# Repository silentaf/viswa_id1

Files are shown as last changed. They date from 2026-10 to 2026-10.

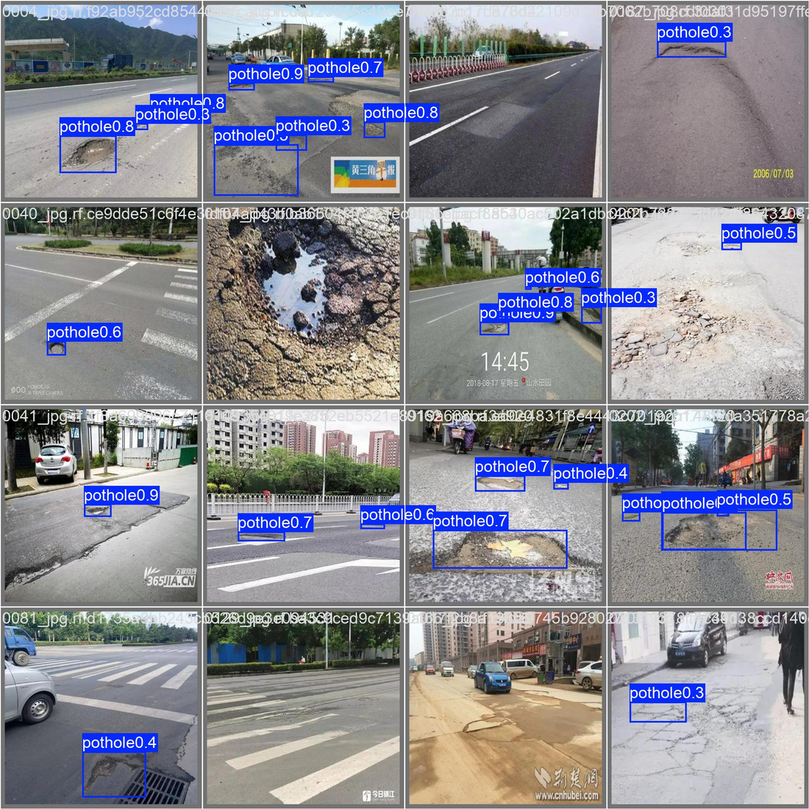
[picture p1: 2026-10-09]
ppt/assets/pothole_test_pred.png

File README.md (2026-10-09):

# VisionAid: Vishwakarma Awards 2026–27 (Team SVNIT)

A chest-worn, fully offline navigation aid for blind and low-vision users that **adds head-level-obstacle and drop-off warnings to the white cane**.
- An **FPGA safety island** (Tang Nano 9K) keeps the alert path running even if the AI computer fails.
- An on-device AI layer (Raspberry Pi 5) names hazards and reads text aloud.

**Stage 2: Design Development.** This repository holds the design files. Nothing has been fabricated yet. Every number is labelled *target*, *calculated*, *simulated*, *cited* or *measured on the development laptop* (Pi software, not a Pi 5); none is a measurement on VisionAid hardware.

| Path | Contents |
|---|---|
| [`VisionAid_Proposal_v2.md`](VisionAid_Proposal_v2.md) | Design specification v2: the Stage 1 proposal corrected, with every change explained |
| [`IMPLEMENTATION_PLAN.md`](IMPLEMENTATION_PLAN.md) | Stage 2 plan, gates, slide map, checklist |
| [`design/electronics/`](design/electronics/) | KiCad 9 carrier board: schematic, PCB, Gerbers, BOM, STEP (ERC 0 / DRC 0) |
| [`design/fpga/`](design/fpga/) | Verilog safety island, testbench (all tests pass), waveforms, Yosys utilisation |
| [`design/cad/`](design/cad/) | FreeCAD parametric chest pod, STEP/STL, renders, mount FEA |
| [`design/bom/`](design/bom/) | Prototype BOM and power budget (xlsx) |

All design files are generated by the scripts in each folder (`scripts/`), so every design decision is written down and reproducible. See [`design/README.md`](design/README.md) for the tools and how to open each file.

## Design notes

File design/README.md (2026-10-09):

# VisionAid: Stage 2 Design Files (index)

**Everything here is design-stage work.** It contains no hardware measurements. Each number is labelled **simulated**, **calculated**, **estimate** or **target**.

| Folder | What | Key result | Feeds slide |
|---|---|---|---|
| `electronics/` | KiCad 9 carrier board: schematic, PCB, Gerbers, BOM, 3D STEP | ERC 0 · DRC 0 · 0 unconnected · parity 0 · 100 % routed | 5, 9, 10, 12 |
| `fpga/` | Verilog safety island, testbench, waveform plots, Yosys utilisation | ALL TESTS PASSED; echo → motor 136 ns on the waveform, ≤ 214 ns testbench bound (simulated); P&R: LUT 17 %, FF 8 %, Fmax 67.9 MHz | 5, 6, 12, 16 |
| `cad/` | FreeCAD parametric pod (`VisionAid_Pod.FCStd`), STEP/STL, renders, mount FEA | 0 mm³ interference; FEA convergence + v1 → v2 iteration | 7, 8, 12 |
| `bom/` | `VisionAid_BOM_Power.xlsx`: prototype BOM + power budget | ₹33,945 at 9 Oct 2026 quotes (₹3,945 over the grant; budget rule inside); 7.2 W → 4.3 h assuming ~50 % AI duty (calculated) | 6, 10 |
| `../VisionAid_Proposal_v2.md` | Corrected Stage 1 document | 15 documented changes | 1–4, 13 |
| `../IMPLEMENTATION_PLAN.md` | Plan, gates, slide map, checklist | — | all |

## Tools (installed locally in `../tools/`, no root needed)

| Tool | Launcher | Used for |
|---|---|---|
| KiCad 9.0.8 | `tools/kicad.sh kicad design/electronics/VisionAid_Carrier.kicad_pro` | Schematic / PCB GUI |
| FreeCAD (conda-forge) | `tools/freecad.sh gui design/cad/VisionAid_Pod.FCStd` | CAD GUI, feature tree, FEM |
| Icarus Verilog, GTKWave, Yosys | `tools/eda.sh <tool>` | Simulation, waveforms, synthesis |
| FreeRouting 2.5 | used by `electronics/scripts/route_pcb.py` | PCB autorouting |

## What YOU must do yourself (judges check authenticity)

1. **Open every design in the GUI and make at least one real edit of your own.** For example: tidy silkscreen in KiCad, change a fillet in FreeCAD, add a comment in the Verilog. Save, then commit.
2. **Take your own screenshots:**
   - FreeCAD with the **feature tree** (BaseShell → ShellProfile sketch, ShellPad, CornerFillet, Hollow, …) and the Params spreadsheet;
   - KiCad PCB editor + 3D viewer + the DRC dialog showing 0 errors;
   - GTKWave with the latency signals;
   - the FreeCAD FEM result.
3. **Photos with your SVNIT ID badge on:** you at the laptop doing CAD / KiCad / simulation, and a review with your faculty guide (photo or video-call screenshot).
4. **Git:** put this `design/` folder in a GitHub repo and commit regularly until 24 Oct. File dates are audited, so do not upload everything on the last day.
5. **Be able to explain every block.** Read `electronics/README.md` and `fpga/README.md`, and the "why" column of the plan.

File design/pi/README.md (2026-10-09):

# VisionAid Raspberry Pi Software (AI path): Proof of Concept

**What this is:**
- The Python application that will run on the Raspberry Pi 5.
- It has been **run and measured on the development laptop** (Intel i7-14650HX, ONNX Runtime limited to 4 threads to match the Pi 5's 4 cores).
- **Speeds are laptop numbers, not Pi 5 numbers.** Expect the Pi 5 to be slower; it will be measured in Stage 3.
- **Accuracy numbers do not depend on the computer.**

| Module | File | Function |
|---|---|---|
| Protocol | `visionaid_pi/protocol.py` | FPGA ↔ Pi UART frames, matching `rtl/va_pilink.v` byte for byte |
| Floor baseline | `visionaid_pi/floor.py` | IMU pitch → expected LiDAR floor range → command to the FPGA (prevents walking-sway false alarms) |
| Vision | `visionaid_pi/vision.py` | YOLOv5n (COCO) on ONNX Runtime; only mobility hazards are named; left / ahead / right from box position |
| Speech | `visionaid_pi/speech.py` | RapidOCR (PP-OCR ONNX) text reading; Piper offline neural TTS (English, Hindi) |
| Alerts | `visionaid_pi/alerts.py` | Priorities: safety > hazard name + FPGA distance > text. The Pi never drives the motors. |
| App | `visionaid_pi/app.py` | Main loop: **event-triggered AI** (runs detection only when the FPGA reports < 3 m), heartbeat, replay mode |

## Measured results (`results/bench_results.json`, `results/detection_accuracy.json`)

| Check | Result | How |
|---|---|---|
| **FPGA ↔ Pi protocol** | **192 frames decoded, 0 bad**; drop-off and fault flags correct; **the Python-built command was accepted by the Verilog FPGA** | Bytes recorded from the Verilog testbench (`../fpga/sim/fpga_to_pi_bytes.hex`); the command bytes come from `protocol.build_command` |
| Detection speed | 28 ms per 640×640 frame (p95 29 ms) | 24 COCO images, laptop |
| **Detection accuracy** | mAP50 **0.41** over 12 hazard classes; **person: AP50 0.65, precision 0.85 and recall 0.54 overall; recall 0.82 for people larger than 96 × 96 px in the image**; weak on bench and truck | 200 COCO val2017 images vs human labels, IoU ≥ 0.5 |
| **OCR accuracy** | **1.9 %** character error (clean), **1.8 %** (blur + tilt + noise); 72–75 % of lines exactly right | 64 rendered labels with known text (synthetic bench test) |
| OCR speed | 1.2–1.4 s per label | laptop |
| TTS | English 150–270 ms, Hindi 85–150 ms to synthesise 1.6–3 s of speech | Piper, laptop |
| **End to end** | camera image → detection → alert → speech WAV ready: **211 ms** mean | laptop |
| Full loop replay | FPGA simulation bytes + images → "Step down ahead. Stop.", "Check device: head sensor.", "person, left, 1.6 metres" | `results/replay/` (log + WAV files) |

**A bug found by the tests and fixed:** OCR word order. Words on one line were sorted by box top, so "BUS STOP" came out as "STOP BUS". Character error went from 25.8 % to 1.9 % after the fix.

**Limitations (honest):**
- Synthetic OCR labels are cleaner than real photos.
- COCO has no Indian classes (auto-rickshaw, open drain).
- Hindi OCR needs a Devanagari model.

All three are Stage 3 work.

## Model training: pothole detector (`training/`)

COCO has no pothole class, so we fine-tuned **YOLO11n** (COCO-pretrained start) on a public pothole dataset
(Roboflow Universe "Potholes Detection", CC BY 4.0, via Hugging Face `Ryukijano/Pothole-detection-Yolov8`;
100 train / 100 valid / 100 test images). Train and test were checked for overlap by file name and by perceptual
hash, including flipped copies: none. 100 epochs on an RTX 5060 laptop GPU took 7.7 min.

| Held-out test split (100 images, 269 potholes) | Result |
|---|---|
| Precision / recall | 0.64 / 0.30 |
| mAP50 / mAP50-95 | 0.37 / 0.15 |
| ONNX speed, laptop CPU, 4 threads (not Pi 5) | 26 ms per image |

Honest limits: a small dataset of mostly non-Indian road photos taken from vehicle or hand height, so recall is low.
Stage 3 needs Indian, chest-height images from our own camera. Files: `training/results/pothole_metrics.json`,
curves, test predictions, `pothole_yolo11n.onnx`. Run: `tools/train-env/bin/python design/pi/training/train_pothole.py`
(from `tools/train-runs/`).

## Run

```
tools/pi-env/bin/python design/pi/bench.py               # benchmark
tools/pi-env/bin/python design/pi/eval_detection.py      # accuracy vs COCO
cd design/pi && ../../tools/pi-env/bin/python -m visionaid_pi.app --replay ../fpga/sim/fpga_to_pi_bytes.hex --images test_data/coco
```

**Test images:** `test_data/coco` is COCO val2017 (Flickr, Creative Commons; cocodataset.org).

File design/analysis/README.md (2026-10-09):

# Design Analyses (calculation and simulation, not hardware measurements)

## `sensor_geometry.py` → `sensor_geometry.png`, `sensor_geometry.json`

**Assumptions:**
- pod height 1.30 m (adult);
- ultrasonic half-beam angle 15°;
- angles taken from the CAD: head sensor +25°, sides ±15°, LiDAR −35°.

**Drop-off warning:**
- The LiDAR meets the floor **1.86 m ahead**.
- A 15 cm step raises the range by 26 cm, so the step is flagged when its edge is about **1.86 m ahead** (≈ 1.5 s at 1.2 m/s).
- **The ≥ 1 m target is met (calculated).**

**Walking sway (simulated):**
- With ±3° chest sway, the floor range swings by up to 30 cm.
- **With a fixed floor baseline there were 25 false alarms in 20 s. With an IMU-compensated baseline there were 0.**
- → Implemented in `design/pi/visionaid_pi/floor.py`. The IMU is required, not optional.

**Coverage gap found:**
- Close to the user (< 1 m ahead), heights **0.3–1.0 m** (waist level) are not covered: the cane covers < 0.3 m and the forward beams reach down to only about 1.0 m there.
- **Fix for CAD v2:** tilt the forward sensors down by 10°.
- Until then, the camera can name such objects but the FPGA reflex path will not catch them.

## `power_range.py` → `power_range.json`

Uses the **published** Pi 5 figures: ≈ 3.0 W idle and ≈ 8.8 W full load (raspberry.tips, 2026). The rest of the system is ≈ 1.3 W (datasheet-level estimates), on a 37 Wh bank at 85 % efficiency.

| Mode | Total | Runtime |
|---|---|---|
| AI running continuously | 10.1 W | **3.1 h** |
| **Event-triggered AI (design choice; AI busy ~50 %, assumed)** | 7.2 W | **4.3 h** |
| AI mostly idle | 4.3 W | 7.2 h |

**Conclusion:** the ≥ 4 h target needs event-triggered AI. This is implemented in `design/pi/visionaid_pi/app.py`.

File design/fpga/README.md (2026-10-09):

# VisionAid FPGA Safety Island (Tang Nano 9K, Verilog)

**Status (8 Oct 2026):**
- Simulation only, so all numbers here are **simulated**, not hardware measurements.
- `run_sim.sh` reports **ALL TESTS PASSED**.

## What it does

| Module | File | Function |
|---|---|---|
| `va_ultrasonic` | `rtl/va_ultrasonic.v` | Fires 3 RCWL-1601 sensors **one at a time** (no crosstalk), 33 ms slots (99 ms per direction). Times the echo in µs and converts it to mm with `(t × 11239) >> 16` = t × 0.1715. Flags a dead or unplugged sensor after 3 missed responses. |
| `va_zone` | `rtl/va_alerts.v` | Distance → zone (info < 3 m, warn < 2 m, urgent < 1 m). Escalates **immediately**; de-escalates with 50 mm hysteresis. |
| `va_haptic` | `rtl/va_alerts.v` | Pulse rate encodes distance: urgent = continuous, warn = 5 Hz, info = 2 Hz. The pattern restarts in its ON phase when the zone escalates, so the motor turns on in the same clock cycle. PWM limits the 3 V motors. |
| `va_lidar` | `rtl/va_alerts.v` | TF-Luna 9-byte frame parser (checksum + signal-strength check). Drop-off = floor reading ≥ 15 cm beyond the calibrated baseline for 3 frames. |
| `va_watchdog` | `rtl/va_alerts.v` | No Pi heartbeat edge for 750 ms → "AI offline" chirp. **Alerts keep working.** |
| `va_pilink` | `rtl/va_pilink.v` | 115200-baud link: status frame to the Pi every 20 ms; commands from the Pi with **clamped** limits (the Pi cannot disable alerts). |
| `visionaid_top` | `rtl/visionaid_top.v` | Ties the blocks together: synchronisers, debouncing, quiet mode (silences only the "info" level), buzzer patterns, LEDs. |

## Simulated results (`sim/sim_results.log`)

| Check | Result |
|---|---|
| Distance 1500 / 2500 mm | 1499 / 2499 mm |
| **Echo edge → motor on** | **136 ns** on the plotted waveform event (motor rises on the same clock as the zone change). The testbench monitor reports **max 214 ns** over 4 events, a conservative bound: it samples the motor 2 clocks after the zone change. Target ≤ 1 ms. |
| Status frames to the Pi | 192 OK, 0 bad (Verilog decoder and Python decoder agree) |
| Drop-off alert | 22.3 ms after the floor reading changed |
| Pi heartbeat lost | AI offline flagged at 666 ms; the obstacle alert still worked |
| Unplugged sensor | fault flag + FAULT_N low |

Figures: `sim/waveform_overview.png`, `sim/waveform_latency_zoom.png` (made by `plot_waveforms.py`).

## Real implementation on the Tang Nano 9K chip (`run_impl.sh` → `impl/`)

The open-source flow ran for **GW1NR-LV9QN88PC6/I5**: Yosys `synth_gowin`, then nextpnr-himbaechel (place and route, timing), then Project Apicula `gowin_pack`.

| Result | Value |
|---|---|
| Timing at the 27 MHz board clock | **PASS**. Fmax **67.9 MHz** (about 2.5× margin) |
| LUT4 | 1,512 / 8,640 (**17 %**) |
| ALU | 914 / 6,480 (14 %) |
| Flip-flops | 568 / 6,480 (**8 %**) |
| I/O | 26 / 276 |
| Bitstream | `impl/visionaid.fs`. Ready to load with openFPGALoader / Gowin programmer when the board arrives. |

## Cross-check in AMD Vivado 2026.1 (`vivado/`)

The same RTL was synthesised and implemented out-of-context on a **Zynq-7020 (xc7z020clg400-1)** at 27 MHz:
- **all timing constraints met, WNS +30.2 ns**;
- 653 LUTs (1.2 %), 580 flip-flops, 1 DSP.

## FPGA ↔ Pi cross-verification

- The testbench sends a command whose bytes were **generated by the Python Pi software** (`tb/pi_cmd_from_python.hex`). The FPGA accepted it (T4).
- Every byte the FPGA transmits is recorded (`sim/fpga_to_pi_bytes.hex`). The Python decoder decodes **192 / 192** frames, matching the Verilog-side decoder.

## Run

```
./run_sim.sh                                                   # ~10 min: simulates 3.9 s of operation
../../tools/eda.sh gtkwave sim/visionaid.vcd                   # waveforms (screenshot for the PPT)
python3 plot_waveforms.py                                      # PNG figures
```

Pin constraints: `constraints/visionaid_tangnano9k.cst`. They match the carrier-board schematic.

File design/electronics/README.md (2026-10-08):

# VisionAid Carrier Board: Electronics Design (v0.1, design stage)

**Status (8 Oct 2026):**
- **Designed and verified in KiCad 9:** ERC 0 violations; DRC 0 violations; 0 unconnected; schematic ↔ PCB parity 0 issues.
- **Not fabricated or tested yet.** Every number below is a design value or target, not a measurement.

## What this board does

It is the **interface and safety-island board** that sits on top of the Raspberry Pi 5 in the chest pod.

| Block | Parts | Why it is designed this way |
|---|---|---|
| **FPGA safety island** | U1 Sipeed Tang Nano 9K (GW1NR-9, 27 MHz) on 2 × 24 sockets | Times all 3 ultrasonic echoes **in parallel** and drives the motors **without the Pi**. If Linux or the AI crashes, obstacle alerts continue (watchdog on `PI_HB`). Only **3.3 V-bank pins** on the left header are used; the right-header pins marked `_1V8` are on a 1.8 V bank and are unused. |
| **Pi link** | J1 2 × 20 header → 40-way IDC ribbon → Pi GPIO | UART (GPIO14/15) for status and config, GPIO17 = heartbeat to the FPGA, GPIO27 = fault from the FPGA, I²C (GPIO2/3) for the IMU. |
| **Power** | F1 500 mA PTC, U2 AMS1117-3.3, C1–C5, D1 SS14 | 5 V comes from the Pi header (the Pi is powered by a BIS-certified USB-C power bank). The PTC protects the Pi's 5 V rail if this board shorts. A separate 3.3 V regulator means the Pi's 3.3 V pins (1, 17) are deliberately **not** used. D1 stops back-feed when the Tang Nano's own USB-C is plugged in for programming. |
| **Sensors** | J2–J4 RCWL-1601 ultrasonic (left, right, head-level), J5 TF-Luna LiDAR (drop-offs), J8 MPU-6050 IMU | RCWL-1601 works at 3.3 V, so there is no level shifting. The TF-Luna takes 5 V but has 3.3 V UART logic. 100 Ω series resistors (R7–R14) limit fault current and ringing on the cables. |
| **Haptics and alarm** | Q1–Q3 AO3400A, R1–R6, D2–D4, J6/J7 coin motors, BZ1 buzzer | Logic-level MOSFETs (V_GS(th) ≤ 1.45 V) are switched directly by the FPGA's 3.3 V PWM. 100 kΩ pull-downs keep the motors off while the FPGA boots. Flyback diodes protect the MOSFETs. The motors (3 V coin ERMs) run from +3V3. |
| **Buttons** | J9 (READ = OCR, MODE, QUIET), R15–R17 10 k pull-ups, C7–C9 100 nF | 10 k × 100 nF ≈ 1 ms RC filter, plus digital debounce in the FPGA. |
| **Test points** | TP1–TP6 (+5V, +3V3, GND, US_L_ECHO, MOT_L_G, PI_HB) | For the Stage 3 logic-analyser measurement of **echo → motor-on latency** and for power checks. |

## FPGA pin map (Tang Nano 9K, 3.3 V banks only)

| Signal | FPGA pin | Signal | FPGA pin |
|---|---|---|---|
| US_L_TRIG / ECHO | 25 / 26 | PI_TXD (FPGA RX) / PI_RXD (FPGA TX) | 40 / 35 |
| US_R_TRIG / ECHO | 27 / 28 | PI_HB (heartbeat in) | 41 |
| US_H_TRIG / ECHO | 29 / 30 | FPGA_FAULT_N (out to Pi) | 42 |
| LIDAR_TX / LIDAR_RX | 33 / 34 | MOT_L_PWM / MOT_R_PWM / BUZZ_EN | 51 / 53 / 54 |
| Clock 27 MHz (on module) | 52 | BTN_READ / MODE / QUIET | 55 / 56 / 57 |

Source: the Sipeed Tang Nano 9K official pin map (wiki.sipeed.com).

## PCB

- **Outline:** 85 × 56 mm, 2 layers, 1.6 mm FR-4. It has the **same outline and M2.5 mounting holes as the Raspberry Pi 5**, and is stacked above the Pi on **20 mm standoffs**. Those clear the Pi's USB/Ethernet jacks and the active cooler; a standard HAT would hit them.
- **Layout:**
  - The Tang Nano sits on 8.5 mm sockets, with its USB-C flush at the right edge for programming.
  - Low-profile SMD parts sit **under** the module, between the socket rows.
  - Sensor connectors are on the bottom edge (cables exit downward towards the sensor windows). Buttons, IMU and motor connectors are on the left edge.
- **Track rules:**
  - 5 V and GND: 0.5 mm.
  - +3V3: 0.3 mm (about 250 mA total load).
  - Signals: 0.25 mm (minimum 0.15 mm, where the router necks down at pads).
  - Clearance 0.2 mm; vias 0.6/0.3 mm.
  - GND pours on both layers.
- **Routing:** FreeRouting v2.5.0 completed 100 %, with 0 violations.

## How the files are produced (reproducible)

All files are generated from scripts so every design decision is written down:

```
tools/kicad.sh python design/electronics/scripts/gen_library.py    # Tang Nano symbol + footprint
python3 design/electronics/scripts/gen_schematic.py                # schematic (.kicad_sch)
tools/kicad.sh kicad-cli sch export netlist -o design/electronics/VisionAid_Carrier.net design/electronics/VisionAid_Carrier.kicad_sch
tools/kicad.sh python design/electronics/scripts/gen_pcb.py        # outline, placement, nets
tools/kicad.sh python design/electronics/scripts/route_pcb.py      # FreeRouting + GND pours
```

Open the project in the KiCad GUI with `tools/kicad.sh kicad design/electronics/VisionAid_Carrier.kicad_pro`.

## Outputs (`outputs/`)

| File | Contents |
|---|---|
| `VisionAid_Carrier_schematic.pdf` / `.svg` | Schematic |
| `VisionAid_Carrier_pcb_top.pdf` / `_bottom.pdf` | Copper and silkscreen plots |
| `gerbers/` | Fabrication files (Gerber X2 + Excellon drill + drill map) |
| `VisionAid_Carrier_BOM.csv` | Bill of materials (on-board parts) |
| `VisionAid_Carrier_pos.csv` | Pick-and-place positions |
| `VisionAid_Carrier.step` | 3D model for the enclosure CAD |
| `pcb_3d_top.png` / `pcb_3d_iso.png` | Board renders with component 3D models (Tang Nano 9K: simplified model in `3d/`) |
| `ERC_report.txt` / `DRC_report.txt` | Verification reports |

## Not on the PCB BOM (buy separately in Stage 3)

- 2 × 1×24 female headers (2.54 mm, 8.5 mm tall) for the Tang Nano.
- 40-way IDC ribbon cable with 2 sockets (≈ 10 cm).
- 4 × M2.5 × 20 mm standoffs and screws.
- JST-XH housings and crimps.
- The sensors, motors and buttons themselves (see the implementation plan, §5).

## Open items before fabrication (Stage 3)

1. **Measure the Tang Nano 9K header row spacing with calipers.** The footprint uses 22.86 mm (0.9″), taken from a community footprint, not an official drawing.
2. Confirm the ribbon length and the standoff height against the enclosure CAD.
3. Check the AMS1117 dropout and temperature at the real load: 5 V → 3.3 V at ~250 mA ≈ 0.43 W in SOT-223.
4. Review the board in the KiCad GUI: tidy silkscreen, then re-run DRC.

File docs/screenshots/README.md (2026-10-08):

# GUI screenshots (8 Oct 2026)

These were captured from the real applications running on a virtual display on the team laptop, using the project files in this repo.

| File | Shows |
|---|---|
| `freecad_01_feature_tree_finger_fillet.png` | FreeCAD PartDesign feature tree; the new `FingerRootFillet` (R 1.5 mm, from the FEA iteration) on the GoPro mount |
| `freecad_02_assembly_iso.png` | Full pod assembly in FreeCAD |
| `freecad_03_params_spreadsheet.png` | Parameter spreadsheet that drives the model |
| `freecad_04_sketch_constraints.png` | Shell profile sketch: **fully constrained**, width/height driven by spreadsheet expressions |
| `kicad_01_pcb_editor_unrouted0.png` | KiCad PCB editor; status bar shows **Unrouted 0** |
| `kicad_02_drc_dialog.png` | KiCad Design Rules Checker: **0 violations, 0 unconnected** |
| `kicad_03_3d_viewer.png` | KiCad 3D viewer with component models, incl. a simplified Tang Nano 9K model made for this project (`design/electronics/3d/`) |
| `kicad_04_schematic.png` | Full schematic |
| `kicad_05_erc_dialog.png` | KiCad Electrical Rules Checker: **0 errors, 0 warnings** |
| `gtkwave_01_echo_to_motor_latency.png` | GTKWave (simulation): left echo falls → distance register = 0x02ED (749 mm) → zone 2 → 3 → left motor ON within a few 37 ns clock cycles |

Still to add, taken by the team: photos with SVNIT ID badges, and the faculty-guide review.

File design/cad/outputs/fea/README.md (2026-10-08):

# Chest-mount FEA (simulation, design stage)

**Tools:** FreeCAD FEM, Gmsh (2nd-order tetrahedra) and CalculiX. Script: `design/cad/scripts/fea_mount.py`. Plots: `plot_fea.py`.

**Model:** a GoPro-style 2-finger mount (3.0 mm fingers, 3.2 mm gap, M5 bolt) on a 30 × 30 mm piece of the 2.5 mm back wall.

**Material:** PETG, E = 2.0 GPa, ν = 0.38. Yield is about 50 MPa (typical datasheet value). Printed parts are weaker between layers, so we **require a factor of safety (FoS) ≥ 3**.

**Boundary conditions:** the bolt-hole faces are fixed (held by the harness buckle). The load is applied on the wall face.

**Load cases (design assumptions):**
- A: **50 N downward.** A ~0.3 kg pod at ~17 g, i.e. a bump or snag.
- B: **20 N sideways.** A side knock, which bends the thin fingers.

## Results (finest mesh that solved)

| Version | Load | Elements | Max von Mises (MPa) | Finger-root (MPa) | FoS on 50 MPa | Max deflection (mm) |
|---|---|---|---|---|---|---|
| v1 sharp roots | A 50 N down | 19,477 | 5.77 | 2.20 | 8.7 | 0.064 |
| v1 sharp roots | B 20 N side | 19,337 | 5.12 | 2.52 | 9.8 | 0.032 |
| v2 1.5 mm root fillet | A 50 N down | 13,572 | 5.74 | 1.76 | 8.7 | 0.062 |
| v2 1.5 mm root fillet | B 20 N side | 13,509 | 4.04 | 2.40 | 12.4 | 0.029 |

## What the convergence study shows (`fea_convergence.png`)

- **v1 (sharp roots):** the finger-root stress **keeps rising as the mesh is refined**: 1.59 → 2.20 MPa under load A and 1.62 → 2.52 MPa under load B. That is the signature of a **stress singularity at a sharp corner**. The true peak in a printed part is set by the corner radius, so the v1 result cannot be trusted.
- **v2 (1.5 mm root fillet):** the root stress **converges** to 1.76–1.82 MPa under A and 2.40–2.42 MPa under B, with < 3 % change across meshes.
- **Design iteration:** v1 → v2 adds 1.5 mm fillets at the finger roots. This is now in the pod CAD as the `FingerRootFillet` feature (8 edges, R 1.5 mm).
- **Where the peak sits:** the highest stress (~4–6 MPa) is at the bolt hole, where the rigid "fixed" support concentrates load. A real bolt spreads that load, so the peak is conservative.
- **Verdict:** every case has **FoS ≥ 8.7** against the ≥ 3 requirement.

## Honest limitations

- The two finest v2 meshes (h = 1.0 mm) **failed to produce a result** (Gmsh/CalculiX on the fillet geometry). The v2 numbers come from 3 mesh levels.
- This is a linear-elastic, isotropic model. Real FDM parts are anisotropic and can creep, so the print orientation should keep the fingers' layers along their length.
- These results are **not** a physical test. In Stage 3 we will do a pull test on a printed mount: hang a known weight and look for cracks.

**Figures:** `fea_convergence.png`, `fea_contour_<version>_<load>.png`.

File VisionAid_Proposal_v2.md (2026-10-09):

# VisionAid: Design Specification v2

**Vishwakarma Awards 2026–27 · Stage 2 (Design Development)**
**Team SVNIT:** Jayant Kumawat (lead), Sneha Ahir, Aman Gupta · SVNIT Surat · Mentor institute: IIT Indore
**Track:** Assistive Solutions & Inclusive Living · **Date:** 9 Oct 2026 · **Status:** design stage, nothing fabricated yet

> **How to read the numbers in this document:**
> - **Target** = a design goal.
> - **Simulated** = from our own simulation files.
> - **Calculated** = from datasheets and arithmetic.
> - **Cited** = from a published source.
> - **Measured (laptop)** = our Pi software run on the development laptop, not on a Pi 5.
>
> No VisionAid hardware has been built, so nothing here is a hardware measurement. Hardware testing is planned for Stage 3.

---

## 1. Title

**VisionAid**: a chest-worn, fully offline navigation aid that adds head-level-obstacle and drop-off warnings to the white cane. An FPGA "safety island" guarantees the alert path even if the AI computer fails, and an on-device AI layer names the hazard and reads text aloud.

## 2. Problem

- In 2020, about **43.3 million people were blind** and **295 million had moderate or severe vision impairment** worldwide *(cited: Bourne et al., Lancet Global Health 2021)*.
- In India, blindness affects **1.99 % of people aged 50 and over** *(cited: National Blindness & Visual Impairment Survey 2015–19)*.
- The white cane only detects what it touches at ground level. In a survey of **307** blind and legally blind travellers, **13 % had head-level accidents at least once a month** and **7 % fell at least once a month**; 23 % of head-level accidents needed medical care, and cane users and guide-dog users did not differ *(cited: Manduchi & Kurniawan, 2011; US-based sample)*.

**What exists today, and the gap:**

| Product | What it does | Price | Gap |
|---|---|---|---|
| **SmartCane (IIT Delhi / Assistech)** | Ultrasonic, above-knee obstacles, vibration on the cane handle | ≈ ₹3,500 (2016) | No drop-off detection, does not identify objects, no text reading |
| OrCam MyEye 3 Pro | Camera on glasses: reading, faces, products | ≈ US$4,250 (US retailer, Oct 2026) | Not a mobility aid; expensive |
| Envision Glasses | AI reading and scene description | US$1,899–3,499 (official shop, Oct 2026) | Not a mobility aid; expensive; some features need the cloud |
| Phone apps (Lookout, RBI MANI, Seeing AI) | Reading and identification | free | Need a hand and a pointed phone; no continuous obstacle warning |

Nothing affordable combines head-level and drop-off warnings with a **bounded alert latency**, on-device object naming and text reading, and fully offline operation, in a form that is worn rather than held.

## 3. Solution (v2)

**Use model:** VisionAid **complements the cane; it does not replace it.** The cane covers the ground at the user's feet. VisionAid covers:
1. obstacles from **waist to head height**, 0.3–3 m ahead (target);
2. **drop-offs** (steps down, kerbs, pits) about 1 m ahead (target);
3. **naming** what is ahead ("person", "car", "dog") and **reading** text when a button is pressed.

### Architecture: two independent paths

```
 3 ultrasonic (left, right, head) ┐                     ┌─► left / right vibration motors (chest straps)
 TF-Luna LiDAR (floor, -35°)      ├─► FPGA SAFETY ISLAND ┤
 buttons                          ┘   Tang Nano 9K       └─► buzzer ("check device")
                                        ▲ UART + heartbeat
 Camera Module 3 ─► RASPBERRY PI 5 (AI path): YOLO-nano objects · OCR · text-to-speech ─► Bluetooth bone-conduction headset
                    power: BIS-certified USB-C power bank
```

- **Safety island (FPGA):**
  - times the three ultrasonic echoes in parallel;
  - reads the LiDAR;
  - classifies distance into zones (info < 3 m, warn < 2 m, urgent < 1 m);
  - drives the motors directly.
  
  **The Pi can tune thresholds but cannot switch alerts off.** If the Pi stops its heartbeat, alerts continue and an "AI offline" chirp sounds.
- **AI path (Pi 5):**
  - names objects (COCO-pretrained YOLO-nano; India-specific classes such as auto-rickshaw, cow, pothole and open drain in Stage 3);
  - OCR on a button press;
  - speech in English and Hindi, with Gujarati as a goal.
- **Feedback:**
  - Haptics are the *safety* channel: wired, so no radio latency. The pulse rate encodes the distance.
  - Speech is the *information* channel, through a bone-conduction headset so the ears stay open to traffic.

## 4. What changed from Stage 1 (and why)

| Stage 1 | v2 | Reason |
|---|---|---|
| PYNQ-Z2 does everything | Pi 5 (AI) + Tang Nano 9K FPGA (safety island) | The Zynq-7020's dual Cortex-A9 cores are too slow for detection plus OCR. The PYNQ-Z2 does not fit the ₹30k grant. Splitting the work isolates faults. |
| "<10 ms" reflex, "<100 ms" on the cover | Per-stage latency specs | An echo from 3 m takes ≈ 17.5 ms to return, so "<10 ms end-to-end" is physically impossible. We specify the part we control: echo → motor. |
| FPGA image pre-processing | FPGA = timing, decision and actuation only | That is where determinism matters. |
| Downward ultrasonic | Downward TF-Luna LiDAR + IMU | A narrow beam gives a clean floor-distance signal. |
| Wristband with 2 motors | Left/right motors on the harness straps | Two motors on one wrist are hard to tell apart. A user test is planned for Stage 3. |
| Custom bone-conduction driver | Bluetooth bone-conduction headset | The Pi 5 has no analog audio. |
| "<₹5,500 BOM" | Prototype BOM ₹33,945 at 9 Oct 2026 quotes + estimates (₹3,945 over the grant; see §6); production estimate in Stage 3 | ₹5,500 was impossible with the Stage 1 hardware. |
| "250M+", "₹4–6 lakh" competitors | Updated cited figures; SmartCane named | Accuracy, and an honest public-search disclosure. |
| 10–15 pilot users | Stage 3, after ethics approval, with an O&M instructor | Honest scope. |
| Mic, caregiver app | Future scope | Not core to safety. |

## 5. Target specifications

| Parameter | Target | Design evidence so far |
|---|---|---|
| Obstacle range (waist–head) | 0.3–3.0 m | Sensor class rating; housings angled: head +25°, sides ±15° (CAD) |
| Distance resolution | ≤ ±5 cm to 2 m | 1 µs echo timing = 0.17 mm resolution *(simulated: 1500 mm → 1499 mm)* |
| **Alert latency (echo edge → motor on)** | ≤ 1 ms | **Simulated: 136 ns on the waveform; ≤ 214 ns testbench bound over 4 events (the monitor samples 2 clocks late)** |
| Update period per direction | ≤ 100 ms | 3 sequenced 33 ms slots = 99 ms *(by design; simulated)* |
| Drop-off warning | ≥ 1.0 m ahead of the step | LiDAR at −35° from chest height; *simulated: alert 22 ms after the floor reading changes* |
| AI offline detection | ≤ 1 s, alerts unaffected | *Simulated: 666 ms; obstacle alert still worked with the Pi offline* |
| Object name spoken | ≤ 1.0 s | Stage 3 measurement |
| OCR read-aloud | ≤ 3 s | Stage 3 measurement |
| Runtime | ≥ 4 h | *Calculated: 7.2 W → 4.3 h on a 10,000 mAh bank, using cited Pi 5 power (3.0 W idle, 8.8 W full load) and assuming the AI is busy ~50 % of the time; 3.1 h if always on* (to be measured) |
| Pod mass | ≤ 250 g | *Estimated: ≈ 156 g of PETG if printed solid (CAD volume 123 cm³ × 1.27 g/cm³; less with normal infill) plus electronics*. Likely over the target; a v2 weight reduction is planned. |

## 6. Hardware (see `design/` for every file)

- **Carrier PCB** (KiCad 9):
  - Pi 5 outline, 85 × 56 mm, 2 layers;
  - FPGA + sensor connectors + MOSFET motor drivers + 3.3 V regulator + 500 mA PTC + test points;
  - **ERC 0 · DRC 0 · 0 unconnected · schematic ↔ PCB parity 0**; Gerbers generated.
- **FPGA logic** (Verilog):
  - **ALL TESTS PASSED** in simulation;
  - **Place and route on the GW1NR-9 (nextpnr):** timing met at 27 MHz (Fmax 67.9 MHz), **17 % of the LUTs and 8 % of the flip-flops**; bitstream generated.
- **Enclosure** (FreeCAD, parametric):
  - 112 × 84 × 48 mm PETG shell (depth raised from 44 mm after the interference check with the real Tang Nano 3D model found a clash), angled sensor housings, GoPro-style mount with 1.5 mm root fillets, vents;
  - **0 mm³ interference** with the electronics *(CAD check)*.
- **Mount FEA** (FreeCAD FEM + CalculiX, PETG; *simulated*):
  - 50 N down and 20 N sideways, worst **factor of safety 8.7** (requirement ≥ 3).
  - The convergence study showed a **stress singularity at the sharp finger roots in v1**; v2 adds **1.5 mm root fillets** and converges.
  - Details: `design/cad/outputs/fea/README.md`.

**Prototype BOM** (`design/bom/VisionAid_BOM_Power.xlsx`, quotes checked 9 Oct 2026): **₹33,945**, ₹3,945 over the ₹30,000 grant. Everything except the Pi 5 board costs ₹19,445, so the Pi 5 4 GB must cost ≤ ₹10,555 to fit; the listings checked were ₹12,600–14,500 and out of stock. The Tang Nano 9K and TF-Luna were also out of stock that day. Plan: re-quote at order time and cover any gap from team funds.

## 7. Safety

- **The alert path is independent of the AI computer**, with a watchdog.
- Sensor faults produce a distinct alarm.
- Quiet mode can only silence the "info" level.
- **No loose lithium cells:** power comes from a BIS-certified power bank.
- A PTC fuse protects the Pi.
- Standards considered in the design (not certification): IEC 62368-1 / IS 13252, IEC 62133-2 / IS 16046, IEC 60529 (IP54 target), ISO 10993 (skin contact), ISO 9999.

## 8. Plan to Stage 3 (4 months)

| Month | Work |
|---|---|
| Nov | Parts and PCB order; FPGA + sensor bring-up; bench tests of range, latency (logic analyser at TP4/TP5) and power |
| Dec | Integration; enclosure print and fit; thermal test; India-class dataset |
| Jan | Ethics approval → supervised trials (sighted blindfolded first, then blind volunteers with an O&M instructor) |
| Feb | Fixes; field-test-ready unit |

## References

1. Bourne R. et al., *Lancet Global Health* 9(2):e130–e143, 2021.
2. National Blindness & Visual Impairment Survey India 2015–19, AIIMS / MoHFW.
3. Manduchi R., Kurniawan S., *Insight* 4(2), 2011 (UCSC-SOE-10-24): 307 respondents.
4. SmartCane, IIT Delhi / Assistech (product information).
5. OrCam MyEye 3 Pro (nelowvision.com listing) and Envision Glasses (shop.letsenvision.com), checked 9 Oct 2026.
6. Sipeed Tang Nano 9K wiki and pin map; Benewake TF-Luna datasheet; Raspberry Pi 5 product brief.

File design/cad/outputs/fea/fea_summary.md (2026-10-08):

| Version | Load | Elements | Max von Mises (MPa) | Finger-root (MPa) | FoS on 50 MPa | Max deflection (mm) |
|---|---|---|---|---|---|---|
| v1_sharp | down50N | 19477 | 5.77 | 2.20 | 8.7 | 0.0637 |
| v1_sharp | side20N | 19337 | 5.12 | 2.52 | 9.8 | 0.0324 |
| v2_fillet1p5 | down50N | 13572 | 5.74 | 1.76 | 8.7 | 0.0615 |
| v2_fillet1p5 | side20N | 13509 | 4.04 | 2.40 | 12.4 | 0.0286 |

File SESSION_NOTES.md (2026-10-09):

# VisionAid: Session Notes (where we are, as of 9 Oct 2026)

**Goal:** Vishwakarma Awards 2026–27 **Stage 2** submission. This is a design-specification PPT on the official template, submitted via the Design Stage Form.
- **Deadline:** 25 Oct 2026, 23:59.
- **Our own target:** submit on 24 Oct.

**Repo:** https://github.com/silentaf/viswa_id1. Push after every change.

## Status right now

**9 Oct: full numbers audit done.** Every deck figure was re-checked against the logs/reports, the citations against their sources, and prices against live listings. Fixes: BOM ₹33,945 (₹3,945 over; Pi 5 / Tang Nano / TF-Luna out of stock), runtime 4.3 h (assumes ~50 % AI duty), latency 136 ns waveform vs ≤ 214 ns testbench bound, Manduchi survey stats, OrCam US$4,250, detection-chart labels. New evidence files: `design/cad/outputs/interference_check_44mm.txt`, `design/electronics/outputs/DRC_ERC_parity_recheck.txt`, `design/pi/results/ocr_word_order_check.txt`. Slide 11 now has the full FPGA/Vivado utilisation table. **New slide 13: pothole detector fine-tuned** (YOLO11n, public CC BY 4.0 data; held-out test P 0.64 / R 0.30 / mAP50 0.37; 26 ms laptop CPU) - `design/pi/training/`, env `tools/train-env` (torch cu128 + ultralytics). Deck = 21 slides. Option open: retrain on a larger dataset (full Roboflow set needs the user's free account). **Next:** user fills IDs + photos, then exports the PDF.

### Done

| Area | Files | Key result |
|---|---|---|
| Plan + corrected proposal | `IMPLEMENTATION_PLAN.md`, `VisionAid_Proposal_v2.md` | 15 changes from Stage 1, with reasons |
| Electronics (KiCad 9) | `design/electronics/` | Carrier board 85×56 mm, ERC 0, DRC 0, parity 0, Gerbers, STEP; Tang Nano 9K 3D model in `3d/` |
| FPGA (Verilog) | `design/fpga/` | Simulation **all pass**; echo → motor 136 ns (waveform), ≤ 214 ns (testbench bound); **real P&R on GW1NR-9: Fmax 67.9 MHz, LUT 17 %, FF 8 %, bitstream `impl/visionaid.fs`**; Vivado xc7z020: WNS +30.2 ns |
| FPGA ↔ Pi cross-check | `design/fpga/tb`, `design/pi` | Python-built command accepted by the Verilog FPGA; Python decodes 192/192 frames |
| Pi software (AI path) | `design/pi/` | YOLOv5n 28 ms/frame, mAP50 0.41 (person: precision 0.85, recall 0.54 overall, 0.82 for people > 96 px); OCR 1.9 % character error; Piper TTS in English and Hindi; end to end 211 ms. **All measured on the laptop (i7-14650HX), NOT a Pi 5.** Event-triggered AI; IMU floor baseline. |
| Analyses | `design/analysis/` | Drop-off warned 1.86 m ahead; sway: 25 false alarms → 0 with IMU; waist-height gap under 1 m (fix: forward sensors −10°, CAD v2); battery 3.1 / **4.3** (~50 % AI duty, assumed) / 7.2 h |
| CAD (FreeCAD) | `design/cad/` | Parametric pod 112×84×48 mm; 0 mm³ interference; FEA v2 worst safety factor 8.7 (all runs ≥ 8.6); 1.5 mm finger-root fillet |
| BOM | `design/bom/VisionAid_BOM_Power.xlsx` | ₹33,945 at 9 Oct quotes, **₹3,945 over the grant**. Pi 5 must be ≤ ₹10,555 to fit; re-quote at order time. |
| Screenshots | `docs/screenshots/` | FreeCAD tree/sketch, KiCad DRC/ERC/3D, GTKWave |
| **PPT** | `ppt/VisionAid_Stage2_Design_Deck.pptx` (20 slides, editable), built by `node ppt/build_deck.js` | Validated and checked visually |

### Pending from the user

1. Application ID + Team ID (slide 1, shown in red).
2. Photos: ID-badge work photo + faculty-guide review (slide 14 placeholders).
3. Their own edits in KiCad/FreeCAD + regular commits until 24 Oct (authenticity).
4. PPT feedback, then export the final PDF (the user does this at the end).

### Open technical items (Stage 3, not now)

- Pi 5 real timings, power and thermal.
- Measure the Tang Nano header spacing with calipers before ordering the PCB.
- CAD v2: forward sensors −10°, weight reduction.
- RISC-V (PicoRV32) + tiny SNN: research extension only.

## How to run things (no root needed; tools live in `tools/`, which is not in git)

- **KiCad:** `tools/kicad.sh kicad design/electronics/VisionAid_Carrier.kicad_pro`. libkicommon is patched so 3D plugins load via `/tmp/vakicad_lib_x86_64gn`.
- **FreeCAD:** `tools/freecad.sh gui|cmd|offscreen <script>`.
- **EDA:** `tools/eda.sh iverilog|vvp|gtkwave|yosys|nextpnr-himbaechel-gowin`.
- **FPGA:**
  - `design/fpga/run_sim.sh` (~10 min)
  - `design/fpga/run_impl.sh` (P&R + bitstream)
  - Vivado: `/opt/Xilinx/2026.1/2026.1/Vivado/bin/vivado -mode batch -source design/fpga/vivado/vivado_crosscheck.tcl`
- **Pi software:**
  - `tools/pi-env/bin/python design/pi/bench.py`
  - `eval_detection.py`
  - `python -m visionaid_pi.app --replay ...`
  - Models live in `/tmp/visionaid-tools/models` (= `tools/models`).
- **Deck:** `node ppt/build_deck.js` (pptxgenjs in `tools/node`). Validate with the pptx skill's `validate.py`, using `tools/freecad-env/bin/python`.
- **Virtual display for GUI screenshots:** `tools/vshot.sh start|grab|xdo|windows` (Xvfb :99).

## User preferences

- Strictly no shortcuts and no faked numbers; label everything as simulated, calculated, measured or cited.
- Work only inside this `submission` folder.
- Keep the PPT editable (PPTX); the PDF comes at the end.
- Keep GitHub updated.

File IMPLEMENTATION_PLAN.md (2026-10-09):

# VisionAid: Stage 2 Implementation Plan

**Team SVNIT** · Vishwakarma Awards 2026–27 · Track: Assistive Solutions & Inclusive Living
**Status: FINAL v1.1 · 8 Oct 2026** (scope corrected: Stage 2 = design-specification deck only). Changes only through the change log at the bottom.
**Deadline:** Stage 2 PPT through the Design Stage Form by **25 Oct 2026, 23:59**. Our own target is to **submit on 24 Oct**. Results are announced in October.

## What this round is

> *Design Specification Stage: shortlisted applicants submit a PPT of design specifications. No prototype video required.*

So Stage 2 is **design work, not a working prototype**. We submit:
- a corrected design (v2);
- target specifications;
- CAD + FEA;
- schematics;
- a sourced BOM;
- safety analysis;
- a roadmap.

All of it goes on the official 20-slide template. **Nothing has to be bought for this round.**

The plan has three parts, in order:
**A. Revise the Stage 1 design (v2)**, then **B. Produce the design files (CAD, FEA, KiCad, BOM, FPGA simulation)**, then **C. Build the PPT on the official template**.

---

## 0. Ground rules

1. **Specs are design targets and must be labelled "Target".** We have no measured results this round, and must not imply any. Every literature number carries a citation.
2. **The template's Maker Journey slide is still audited.** It asks for photos with ID badges, screenshots of CAD/KiCad/FEA work, and a Drive/GitHub link whose **file timestamps are checked**. So every design file goes into **one Git repo + one Drive folder from 8–9 Oct**, committed as work happens.
3. **No stock image is presented as our work.** Every borrowed image goes on the "Image Sources" slide.
4. **VisionAid complements the white cane; it does not replace it.**
5. **BOM prices are quotes** (seller link + date checked), not purchases, and are labelled that way.

---

## 1. Calendar

| Dates | Note |
|---|---|
| Thu 8 – Sat 10 Oct | Repo, Proposal v2, start CAD / KiCad / Verilog |
| **Sun 11 – Mon 19 Oct: Navratri** | Evenings light |
| **Tue 20 Oct: Dussehra** | Light day |
| Sat 24 Oct | **Our submission day** |
| Sun 25 Oct | Buffer only (official deadline 23:59) |

🔸 **Team:** add the SVNIT mid-semester exam dates.

---

## 2. Part A: What changes from Stage 1 → v2 (and why)

These become the **"Stage 1 → Stage 2 Engineering Iterations"** slide.

| # | Stage 1 said | v2 decision 🔒 | Why |
|---|---|---|---|
| C1 | PYNQ-Z2 (Zynq-7020) does everything | **Raspberry Pi 5 (AI path) + Sipeed Tang Nano 9K FPGA (safety island)** | The Zynq-7020's dual Cortex-A9 cores are too slow for object detection **and** OCR on CPU, which is what Stage 1 planned; the Pi 5 (4× Cortex-A76) is far faster. The PYNQ-Z2 doesn't fit the ₹30k grant. The split gives **fault independence**: if the AI computer crashes, the FPGA alert path keeps running. |
| C2 | FPGA also does image pre-processing | **FPGA = safety island only**: parallel ultrasonic + LiDAR timing, threshold/priority logic, haptic PWM, watchdog, sensor-fault detection | Routing the camera through the FPGA adds work with no clear gain at this scale; determinism matters most in the alert path. |
| C3 | Cover "<100 ms"; body "<10 ms reflex, <150 ms full" | **Per-stage latency targets** (§4) | Physics: an echo from 3 m takes ≈ 17.5 ms to return (sound ≈ 343 m/s), so "<10 ms end-to-end" is impossible. We specify the part we control: **echo received → motor on**. |
| C4 | "Hands-free unlike a cane"; obstacles "below chest height" | **Cane-complement:** covers **waist-to-head obstacles** and **drop-offs ahead**; the cane stays primary for the ground | Head-level collisions and falls are the documented gap (Manduchi & Kurniawan 2011). This is also the safe positioning. |
| C5 | Downward ultrasonic for drop-offs | **Downward ToF LiDAR (Benewake TF-Luna)** + IMU pitch compensation | The wide ultrasonic beam picks up ground clutter; a narrow LiDAR beam gives a clean distance-to-ground. |
| C6 | Wristband, two motors (L/R) | **L/R motors on the chest-harness straps, wired to the FPGA** | Motors a few cm apart on one wrist are hard to tell apart; wiring keeps radio latency out of the safety path. (L/R test planned for Stage 3.) |
| C7 | Custom bone-conduction driver | **Bluetooth bone-conduction headset** | The Pi 5 has no analog audio; speech is the information channel, haptics the safety channel. |
| C8 | Chest-clip, no mechanical detail | **Chest pod on a GoPro-style harness**; power bank in a pocket; **PETG** enclosure; IP54 target | Proven, cheap mount. PLA softens at Indian summer temperatures (Tg ≈ 60 °C); PETG doesn't (Tg ≈ 80 °C). |
| C9 | "<₹5,500 BOM" | **Prototype BOM from quotes (≈ ₹22–30k)** + a **production-intent BOM estimate** at 1k units | The ₹5,500 figure was impossible with a PYNQ-Z2 alone. |
| C10 | "250M+"; competitors "₹4–6 lakh" | **43.3 M blind + 295 M with moderate/severe impairment (2020)**; India: **1.99 % blindness among people aged 50+** (NBVIS 2015–19); OrCam MyEye 3 Pro ≈ US$4,250 (US retailer); Envision US$1,899–3,499; **SmartCane (IIT Delhi, ≈ ₹3,500) named as our closest Indian competitor** | Current, citable numbers, plus an honest public-search disclosure. |
| C11 | MEMS mic for horns/alarms | **Future scope** | Not core to the safety function. |
| C12 | Caregiver app | **Future scope** | Not core. |
| C13 | 10–15 pilot users via EnAble India / NAB | **Trials in Stage 3 after ethics approval**, with an O&M instructor; partners listed as "outreach in progress" unless they confirm | Honest scope. |
| C14 | Language not stated | **English + Hindi**, Gujarati as a goal | India-first. |
| C15 | Model/classes not stated | **COCO-pretrained YOLO-nano** now; **India-specific fine-tune** (auto-rickshaw, cow, pothole, open drain; IDD dataset) in Stage 3 | Realistic, with a clear novelty path. |

**Core innovation (one line, slide 1):**
*A chest-worn, fully offline navigation aid that adds head-level-obstacle and drop-off warnings to the white cane. Its alert latency is bounded by an FPGA "safety island" that keeps working even if the AI computer fails, and an on-device AI layer names the hazard and reads text aloud.*

---

## 3. v2 architecture

```
                     ┌──────────── CHEST POD (PETG, GoPro-style mount) ────────────┐
 3× ultrasonic ──────┤► Tang Nano 9K FPGA = SAFETY ISLAND                          │
 (fwd-L, fwd-R, head)│   trigger sequencer → echo timers → distance → zone compare │──► L/R haptic motors
 TF-Luna LiDAR (down)┤►  LiDAR UART parser → drop-off detector                     │    (MOSFET + PWM patterns)
 buttons ────────────┤►  priority encoder · pattern generator · watchdog · fault   │──► piezo buzzer ("check device")
                     │        ▲ UART (status 50 Hz / config) │ heartbeat            │
                     │        ▼                              ▼                      │
 Camera Module 3 ────┤► Raspberry Pi 5 = AI PATH                                   │
 IMU (I²C) ──────────┤►  YOLO-nano objects · OCR on button · alert manager · TTS   │──► BT bone-conduction headset
                     └──────────────────────────────▲──────────────────────────────┘
                                         USB-C 5 V power bank (pocket)
```

**Rule:** the FPGA drives the motors itself, and the Pi only *adds* information. If the Pi's heartbeat stops, the FPGA keeps the alerts running and gives an "AI offline" cue.

---

## 4. Target specifications (all TARGETS; how each is verified in Stage 3)

| Parameter | Target | Basis / Stage 3 verification |
|---|---|---|
| Obstacle range (waist–head height) | 0.3 – 3.0 m | Sensor datasheet; tape-measure test |
| Range error | ≤ ± 5 cm up to 2 m | Datasheet; 20 readings per step |
| **Alert latency** (echo edge → motor on) | ≤ 1 ms worst case | FPGA simulation now (B5); logic analyser later |
| Update period per direction (3 sensors sequenced) | ≤ 100 ms | Calculated from echo time + guard interval |
| Drop-off (≥ 15 cm step) detected ahead | ≥ 1.0 m before the step | Geometry (LiDAR angle, §B2 calc); stair test |
| Object label spoken | ≤ 1.0 s | Laptop benchmark now (optional); Pi 5 later |
| OCR read-aloud (short label) | ≤ 3 s | Same |
| Runtime on a 10,000 mAh bank | ≥ 4 h | **Power budget calculation** (B3) |
| Pi temperature in the closed pod | No throttling | Vent/cooler design; thermal test later |
| Chest pod mass | ≤ 250 g | CAD mass properties (B1) |
| Pi failure → "AI offline" cue | ≤ 1 s | Watchdog in FPGA simulation (B5) |

Some of these can be **backed by calculation or simulation this round**: alert latency, update period, drop-off geometry, runtime and mass. Say so on the slide ("simulated" / "calculated"), never "measured".

---

## 5. Part B: Design files to produce (8–21 Oct)

| ID | Deliverable | Tool | Owner | Due | Feeds slide |
|---|---|---|---|---|---|
| B0 | GitHub repo (`cad/ hw/ fpga/ sw/ docs/`) + Drive folder with **view access**; first commit today | GitHub | R1 | **8–9 Oct** | 12 |
| B1 | **3D CAD** of the chest pod: Pi 5, Tang Nano, camera, 3 ultrasonic windows, LiDAR angled down, vents + cooler, button layout, GoPro-style mount fingers, strap motor clips. Use official Pi 5 / sensor STEP files. Isometric + exploded renders; mass properties. | Fusion 360 (student licence) | R3 | 16 Oct | 7, 12 |
| B2 | **Sensor geometry calc**: mounting angles for the head-level sensor and the LiDAR, coverage cones vs body height (sketch + numbers) | Fusion / spreadsheet | R3 + Claude | 14 Oct | 6, 7 |
| B3 | **Power budget**: datasheet current per component → total W → runtime on 10,000 mAh | Spreadsheet | R2 + Claude | 15 Oct | 6, 9 |
| B4 | **FEA**: mount fingers + strap slot. Loads: 50 N strap tension; 0.3 kg × 10 g jolt ≈ 30 N. Target FoS ≥ 3 in PETG. Adaptive-mesh **convergence plot**. **At least one design iteration** (e.g. fillet / thickness change). Material comparison PLA vs PETG vs ASA. | Fusion Simulation | R3 | 19 Oct | 8, 12 |
| B5 | **FPGA design in simulation**: echo timer, trigger sequencer, zone compare, TF-Luna parser, drop-off detector, PWM patterns, watchdog. Testbench shows **echo → motor-on latency in clock cycles** and the watchdog timeout. Synthesis report for LUT/BRAM usage on the GW1NR-9. | Gowin EDA + Icarus Verilog / GTKWave | R1 | 18 Oct | 6, 12, 16 |
| B6 | **KiCad schematic** of the carrier board (Pi header, Tang Nano headers, sensor JST connectors, MOSFET motor drivers + flyback diodes, buzzer, buttons, 5 V/3.3 V power tree) + ERC | KiCad | R1 | 16 Oct | 9 |
| B7 | **KiCad PCB layout** + **DRC report** | KiCad | R1 | 20 Oct | 9, 12 |
| B8 | **BOM spreadsheet**: part number, qty, quoted price + link + date checked, local/imported, lead time; prototype total + production-intent estimate | Sheets/Excel | R2 + Claude | 20 Oct | 10 |
| B9 | **Software design**: flow chart of the AI path (camera → YOLO → alert manager → TTS; OCR button flow) and the alert-priority state machine. *Optional:* run YOLO/OCR on a laptop with sample images for indicative timings (labelled "laptop, not target hardware"). | draw.io / Python | R2 | 18 Oct | 5, 6 |
| B10 | **FMEA table + standards list** (§7) | Sheets | R2 + Claude | 20 Oct | 14 |
| B11 | **User-journey storyboards** (before/after) + quantified pain from literature. *Optional:* 2–3 phone interviews with blind users (with consent) via Blind People's Association Ahmedabad / NAB Gujarat | Slides / draw.io | R3 | 19 Oct | 3, 4 |
| B12 | **Maker-journey photos**: team **with ID badges** doing CAD, KiCad, simulation, plus a **review with the faculty guide/mentor** (photo or video-call screenshot) | Phone | R3 | 21 Oct | 11 |

**Part A task:**
- **A1, Proposal v2.** Revise the Stage 1 document with C1–C15. Owner: Claude, then team review. Due 11 Oct.

**Optional (only if the team wants stronger maker photos and has ~₹3–5k):** buy a Tang Nano 9K + 2 ultrasonic sensors + 1 motor and show a bench demo of the alert path. This is **not required** for this round. Everything else goes on the Stage 3 order.

---

## 6. Roles (🔸 team to confirm names)

**Update 8 Oct: Aman is working solo.** Claude generates first drafts of every design file (CAD script, KiCad schematic/PCB, Verilog + testbench, calculations, BOM, FMEA, slide text). Aman opens, reviews, modifies and screenshots each one personally, and must be able to explain every part to the judges.

| Who | Owns |
|---|---|
| **Aman** | Install tools; review and edit all files in KiCad / FreeCAD / GTKWave; screenshots; ID-badge photos + mentor review; repo commits; final PPT assembly and submission |
| **Claude** | Drafts of A1 and B1–B11; calculations; slide content; final number check |

---

## 7. Safety content (slide 14)

**FMEA seed:**

| Failure | Effect | Design response |
|---|---|---|
| Ultrasonic stuck / no echo | Missed obstacle | Timeout detector → buzzer "check device" pattern |
| Pi crash / hang | No object names or OCR | FPGA watchdog → "AI offline" cue; alert path unaffected |
| BT headset disconnects | No speech | Haptics continue; distinct cue |
| Harness tilt shifts the LiDAR baseline | False or missed drop-off | Stand-still calibration + IMU pitch check |
| Pi overheats | Throttling, slow AI | Active cooler + vents in the CAD |
| Power bank low | Device stops | Spoken warnings at 20 % / 10 % |
| Battery fire | Burn | Only a BIS-certified power bank; no loose Li-ion cells |
| Alert fatigue | User ignores alerts | Zone hysteresis + quiet mode |

**Standards considered in design (not "certified"):**
- IEC 62368-1 / IS 13252 (ICT equipment safety).
- IEC 62133-2 / IS 16046 (Li-ion batteries).
- IEC 60529 (IP54 target).
- ISO 10993-5/-10 (skin-contact materials).
- ISO 9999 (assistive product classification).
- WPC/ETA (pre-certified radio modules only).

---

## 8. Part C: PPT (21–24 Oct)

| ID | Task | Owner | Due |
|---|---|---|---|
| P1 | Freeze numbers: each one labelled target / calculated / simulated / cited, with its source in `docs/numbers.md` | Claude + all | 21 Oct |
| P2 | Draft content for every slide (map below) | Claude | 22 Oct |
| P3 | Build in a **copy of the official template**; delete the example slides | R3 | 23 Oct |
| P4 | Review against the checklist; fix | all + Claude | 23 Oct |
| P5 | Export PDF, test links in incognito, **submit** | Team lead | **24 Oct** |

**Slide map:**

| # | Template slide | Our content |
|---|---|---|
| 1 | Project overview | Application ID 🔸, Team ID 🔸, Track, one-line innovation |
| 2 | Problem statement | Cane gap; 43.3 M / 295 M; NBVIS India; SmartCane + premium devices disclosure |
| 3 | User journey: before | Storyboard + quantified pain (cited) |
| 4 | User journey: after | Storyboard + **target** gains |
| 5 | System block diagram | §3 diagram, drawn properly |
| 6 | Specs + hardware selection | §4 targets + basis; part choices + rationale (C1, C2, C5) |
| 7 | CAD renders | Isometric + exploded (B1); sensor cones (B2) |
| 8 | Materials + FEA | PETG vs PLA vs ASA; stress/FoS; iteration (B4) |
| 9 | Schematics + power | KiCad schematic + power tree + power budget (B3, B6, B7) |
| 10 | BOM + sourcing | Quotes, local/imported, lead times (B8) |
| 11 | Maker journey: photos | ID-badge photos, mentor review (B12) |
| 12 | Maker journey: evidence | Fusion feature tree, FEA convergence, KiCad DRC, FPGA sim waveform, repo link |
| 13 | Stage 1 → 2 iterations | Strongest 6–8 of C1–C15 |
| 14 | Safety | FMEA + standards (§7) |
| 15 | Roadmap + Stage 3 commitment | §9 |
| 16 | Technical challenges | Ultrasonic crosstalk, LiDAR in sunlight, Pi heat in a closed pod, harness tilt, alert fatigue |
| 17 | Mitigations | Matching design responses |
| 18 | References & image sources | All citations and image URLs |

**Checklist:**
- [ ] Every number is labelled target / calculated / simulated / cited
- [ ] Nothing says "measured" or "tested"
- [ ] No "<10 ms end-to-end", "<₹5,500" or "250M+" left from Stage 1
- [ ] SmartCane and the premium devices are named
- [ ] ID-badge photos + mentor review photo included
- [ ] Repo/Drive opens in incognito; native files present (`.f3d/.step`, `.kicad_sch/.kicad_pcb`, `.v`, BOM `.xlsx`); timestamps fall 8–24 Oct
- [ ] No embedded videos
- [ ] Template example slides removed
- [ ] Image sources complete
- [ ] PDF within the form's size limit 🔸

---

## 9. Gates

| Gate | Date | Pass | If it fails |
|---|---|---|---|
| G0 | 9 Oct | Repo live; roles assigned; Fusion/KiCad/Gowin installed | Fix the same day |
| G1 | 16 Oct | CAD v1, schematic v1, Proposal v2, power budget done | Drop PCB layout (B7); show the schematic only |
| G2 | 21 Oct | FEA, FPGA sim, BOM, FMEA, photos done | Cut optional items (B9 laptop run, interviews) |
| G3 | 23 Oct | Slides complete; checklist clean | 24 Oct is the fix day |

---

## 10. Stage 3 roadmap (4 months, slide 15)

| Month | Work |
|---|---|
| **Nov 2026** (Diwali 8 Nov) | Order parts; bring up the FPGA + sensors + Pi; carrier PCB fabrication; file the ethics application |
| **Dec 2026** | Integration; enclosure print; bench tests (range, latency, drop-off, power, thermal) |
| **Jan 2027** | India-class fine-tune; supervised trials (sighted blindfolded first, then blind volunteers with an O&M instructor, after approval) |
| **Feb 2027** | Fix the top issues; field-test-ready unit |

**Stage 3 commitment:** a wearable, battery-powered prototype ready for supervised functional field testing, with every §4 target measured.

**Stage 3 parts budget** (re-checked 9 Oct 2026; see `design/bom/VisionAid_BOM_Power.xlsx`): Pi 5 4 GB ₹12,600–14,500 (out of stock) · Camera Module 3 ₹3,158 · Tang Nano 9K ₹2,999 (out of stock) · TF-Luna ₹2,118 (out of stock) · rest estimated → **₹33,945 total, ₹3,945 over the grant**.

---

## 11. 🔸 Team inputs needed

| # | Input | Default |
|---|---|---|
| 1 | Application ID + Team ID | Placeholder |
| 2 | Names for R2 / R3 | — |
| 3 | SVNIT faculty guide + IIT Indore mentor | Needed for the review photo |
| 4 | Mid-semester exam dates | — |
| 5 | Optional bench demo (~₹3–5k)? | No |

---

## References (verified 8 Oct 2026)

- Bourne R. et al., Lancet Global Health 9(2):e130–e143, 2021. https://pubmed.ncbi.nlm.nih.gov/33275950/
- NBVIS India 2015–2019 (AIIMS / MoHFW). https://indiavisionatlasnpcb.aiims.edu/?p=358
- Manduchi R., Kurniawan S., Insight 4(2), 2011 (UCSC-SOE-10-24). https://tr.soe.ucsc.edu/research/technical-reports/UCSC-SOE-10-24
- SmartCane (IIT Delhi / Assistech). https://www.electronicsforu.com/electronics-startups/innovations-innovators/smartcane-indigenous-device-help-visually-impaired-2
- OrCam MyEye 3 Pro: https://www.orcam.com/en-us/orcam-myeye-lp-for-people-who-are-blind-or-visually-impaired · Envision: https://support.letsenvision.com/hc/en-us/articles/7602816580369
- Parts: https://probots.co.in/sipeed-tang-nano-9k-fpga-development-board.html · https://probots.co.in/benewake-tf-luna-lidar-distance-sensor-8m-uart.html · https://thingbits.in/products/raspberry-pi-camera-module-3

---

## Change log

| Date | Change | Reason |
|---|---|---|
| 8 Oct 2026 | v1.0 | Initial plan |
| 9 Oct 2026 | Numbers audit: every deck figure re-checked against logs/reports; prices re-quoted (BOM ₹33,945); citations re-verified | User: "everything real, verified, and correct" |
| 8 Oct 2026 | v1.1: scope cut to design-specification deck; no purchases or physical tests in Stage 2; specs as targets backed by calculation/simulation; build moved to the Stage 3 roadmap | Organisers: "PPT of design specifications… No prototype video required" |

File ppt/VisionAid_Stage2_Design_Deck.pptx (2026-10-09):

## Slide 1

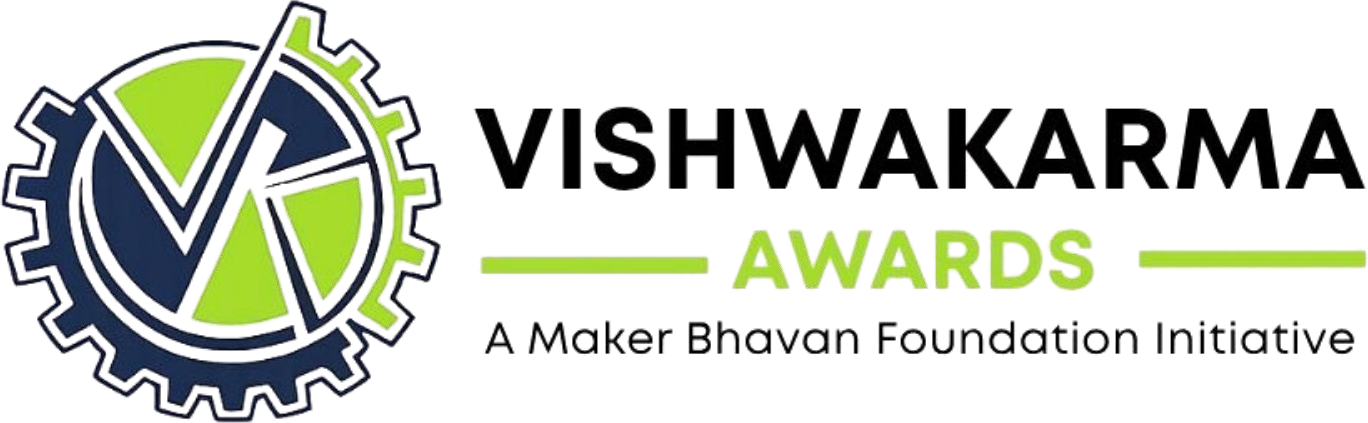
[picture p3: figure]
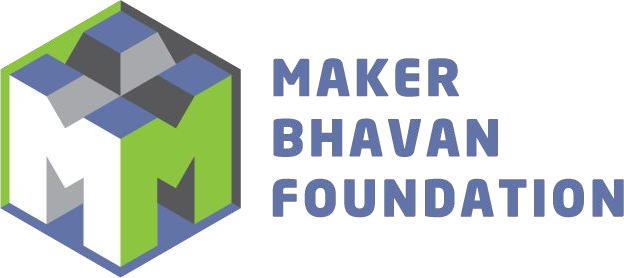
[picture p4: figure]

VISHWAKARMA AWARDS 2026-27 · STAGE 2 DESIGN SPECIFICATION

Vishwakarma Application ID: [add before submission]

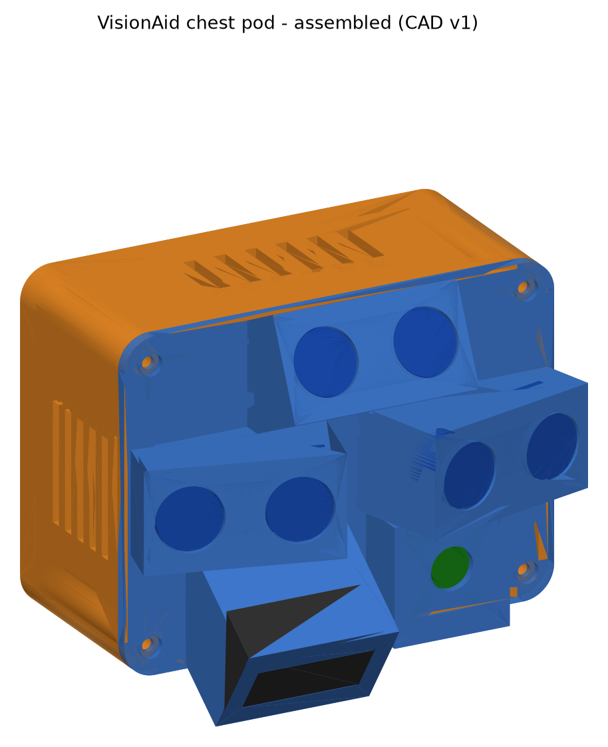
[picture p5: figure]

CAD v1 of the chest pod (FreeCAD) - design stage, not yet fabricated

VisionAid

A chest-worn, fully offline navigation aid that adds head-level-obstacle and drop-off warnings to the white cane - with an FPGA "safety island" whose alerts keep working even if the AI computer fails.

Team ID: [add before submission]
Track: Assistive Solutions & Inclusive Living
Team SVNIT: Jayant Kumawat (lead), Sneha Ahir, Aman Gupta - SVNIT Surat
Mentor institute: IIT Indore
Design files: github.com/silentaf/viswa_id1

## Problem Context

43.3 M

people blind worldwide (2020)

Cited: Bourne et al., Lancet GH 2021

295 M

moderate / severe vision impairment

Cited: Bourne et al., Lancet GH 2021

1.99 %

blindness among Indians aged 50+

Cited: NBVIS India 2015-19

₹3,500

SmartCane - closest Indian aid

Cited: IIT Delhi / Assistech

Problem statement
- The white cane only senses what it touches at ground level, about one cane-length ahead.
- Head-level obstacles (branches, poles, signs, truck bodies) and drop-offs (open drains, kerbs, steps) are what it misses. In a survey of 307 blind / legally blind travellers, 13 % hit their head at least once a month and 7 % fell at least once a month; 23 % of head-level accidents needed medical care, and cane vs guide-dog users did not differ (cited: Manduchi & Kurniawan, 2011; US-based sample).
- Reading a label or sign still needs a sighted helper or a hand-held phone.
- Target beneficiary: blind and low-vision cane users who walk independently on Indian streets and campuses.

Public search disclosure - what exists

Product | Price (cited) | Gap
SmartCane (IIT Delhi) | ≈ ₹3,500 (2016) | Above-knee only; no drop-offs, no naming / reading
OrCam MyEye 3 Pro | ≈ US$4,250 | Reading aid, not mobility; expensive
Envision Glasses | US$1,899-3,499 | Reading / description; expensive
Phone apps (Lookout, MANI) | free | Need a hand + pointed phone; no continuous warning

Core innovation: head-level + drop-off warnings for the cane user, with an alert path bounded in hardware (FPGA) and an on-device AI layer that names hazards and reads text - fully offline.

## User Journey - Before (cane only)

Walks with cane

cane sweeps the ground ~1 m ahead

Head-level obstacle

not touched by the cane

Collision

head / face injury risk

Open drain or step down

found only when the cane drops in

Needs to read a label

asks a stranger / holds a phone

Current pain points
- Warning comes from contact: the cane reports an obstacle only when it touches it.
- Nothing above the cane: overhanging objects are invisible to it.
- Drop-offs are found by falling-in of the cane tip - the user is already at the edge.
- Reading and identifying objects depend on another person.

Quantified inefficiency (calculated, not measured)
- Warning time for ground obstacles: ~1 m cane reach ÷ 1.2 m/s walking speed ≈ 0.8 s.
- Warning time for head-level obstacles: 0 s - the cane never touches them.
- Warning before a drop-off: only as far as the cane tip; no advance cue.
- Text: every label / sign needs a helper; no independent reading.

Assumptions: 1.2 m/s typical adult walking speed and ~1 m cane reach are design assumptions; Stage 3 user interviews and trials will replace them with measured values.

## User Journey - After (cane + VisionAid)

Walks with cane + pod

pod scans 0.3-3 m, waist to head

Obstacle in 3 m

FPGA classifies distance zone

L / R vibration

pulse rate = distance; side = direction

Floor drops ahead

LiDAR: drop-off alarm + buzzer

Presses READ

Pi reads text aloud (offline)

How the user benefits
- Warned before contact - including head-level obstacles the cane cannot reach.
- Left / right motors on the chest straps say which side the hazard is on.
- Drop-off warning ahead of the edge, not at it.
- Hands stay free; speech through a bone-conduction headset keeps the ears open to traffic.
- Alerts never depend on the AI computer (FPGA safety island).

Quantified efficiency (labels say where each number comes from)
- Warning time, 3 m range at 1.2 m/s: ≈ 2.5 s (calculated, target range)
- Echo edge → motor on: max 214 ns over 4 events (simulated; target ≤ 1 ms)
- Update per direction: 99 ms (by design, simulated)
- Drop-off warned: 1.86 m before the step (calculated from CAD angles); alert 22 ms after (simulated)
- Image → speech audio ready: 211 ms (measured on laptop, not Pi 5; excludes capture + playback)

Honesty rule: no hardware built yet - simulated = our Verilog testbench; measured = our Pi software run on the dev laptop; Pi 5 and field numbers come in Stage 3.

## System Architecture - Block Diagram

3 × RCWL-1601 ultrasonic
(left, right, head-level)

FPGA SAFETY ISLAND
Sipeed Tang Nano 9K (27 MHz)
echo timing · distance zones
LiDAR drop-off · PWM patterns
watchdog · fault detection

Left / right coin motors
(chest straps, wired)

POWER
BIS-certified
USB-C power bank
→ Pi 5
→ 500 mA PTC
→ carrier 5 V
→ AMS1117 3.3 V

TF-Luna LiDAR
(floor, −35°)

Buzzer
("check device", drop-off)

3 buttons
(READ / MODE / QUIET)

UART 115200 status / config
+ heartbeat + fault line

Camera Module 3
(autofocus)

AI PATH - Raspberry Pi 5
YOLO-nano object names · OCR
text-to-speech (EN / HI)

Bluetooth bone-conduction
headset (speech)

Safety rule: the FPGA drives the motors itself; the Pi can only add information and tune thresholds within clamped limits (it cannot switch alerts off). If the Pi's heartbeat stops, alerts continue and an "AI offline" chirp sounds.

## Target Specifications & Hardware Selection

Parameter | Target | Evidence so far | Selected hardware / protocol
Obstacle range (waist-head) | 0.3-3.0 m | sensor class; housings +25° / ±15° (CAD) | 3 × RCWL-1601, 3.3 V, sequenced
Alert latency (echo → motor) | ≤ 1 ms | Simulated: max 214 ns (4 events) | Tang Nano 9K GW1NR-9 FPGA, 27 MHz
Update period / direction | ≤ 100 ms | 99 ms by design (simulated) | 3 × 33 ms slots (no crosstalk)
Distance resolution | ≤ ±5 cm to 2 m | Timer logic simulated: 1500 → 1499 mm (sensor error: Stage 3) | 1 µs echo timer (0.17 mm/count)
Drop-off warning | ≥ 1.0 m ahead | Calculated 1.86 m (−35° from 1.3 m); alert 22 ms (sim.) | Benewake TF-Luna + IMU tilt correction
Object name / OCR | ≤ 1 s / ≤ 3 s | Laptop: detect 28 ms, e2e 211 ms, OCR 1.2-1.4 s | Raspberry Pi 5 4 GB + Camera Module 3
Pi fails → alert path | unaffected, cue ≤ 1 s | Simulated: AI-offline at 666 ms | FPGA heartbeat watchdog (GPIO17)
Runtime | ≥ 4 h | Calc. (cited Pi 5 W): 4.3 h if AI busy ~50 % (assumed); 3.1 h if always on | 10,000 mAh BIS power bank, USB-C
Pod mass | ≤ 250 g | Estimate: likely over (plastic ≈156 g solid) | PETG, 2.5 mm wall; lightening in v2

Architecture rationale: Pi 5 (4 × Cortex-A76, 2.4 GHz) instead of the Stage 1 PYNQ-Z2 (2 × Cortex-A9, 650 MHz) for detection + OCR; FPGA kept for the parallel, cycle-exact, fault-isolated alert path; wired haptics so no radio sits in the safety path.

## CAD Design & Mechanical Specs

FREECAD · PARAMETRIC

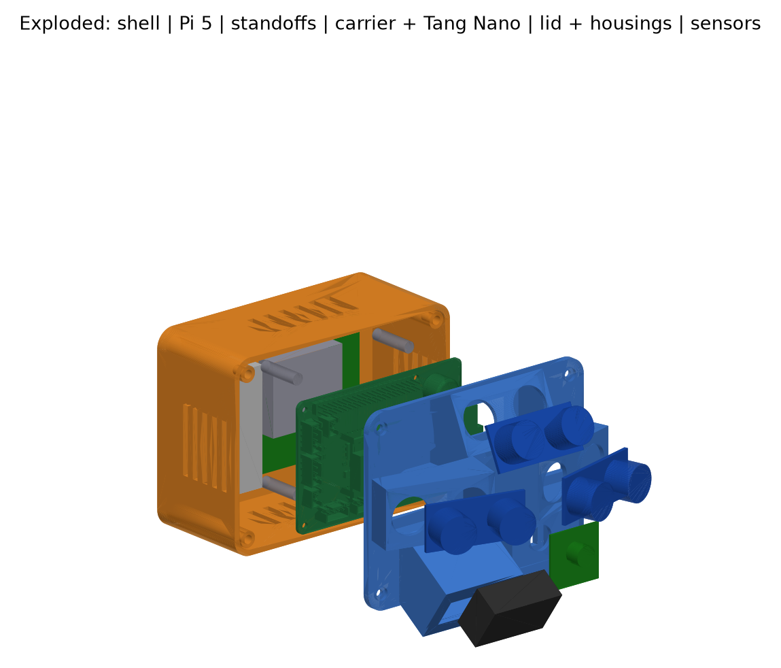
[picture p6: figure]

Exploded: shell | Pi 5 | 20 mm standoffs | carrier PCB + Tang Nano | lid + housings | sensors

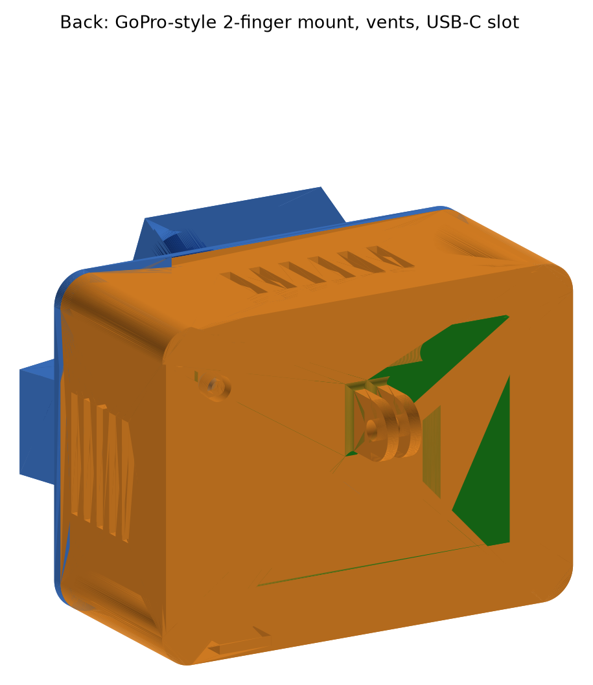
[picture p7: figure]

Back: GoPro-style mount, vents

Mechanical specification
- Envelope: 112 × 84 × 48 mm shell + front housings
- Model: 19-parameter spreadsheet drives the model; shell sketch fully constrained
- Housings: head sensor +25°, side sensors ±15° yaw, LiDAR −35°
- Mount: GoPro-style 2-finger (3 mm, M5) on a chest harness
- Cooling: side + top/bottom vents for the Pi 5 active cooler
- Interference check: 0 mm³ vs Pi, carrier, Tang Nano, sensors

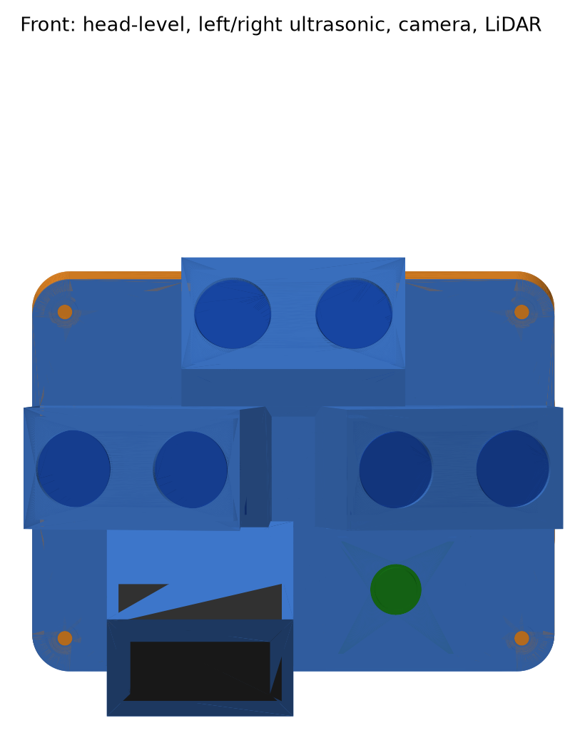
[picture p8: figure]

Front: sensor housings

Design iteration: adding the Tang Nano 3D model showed a 182 mm³ clash with the lid (171 mm³ of it the HDMI connector) - shell depth raised 44 → 48 mm in one parameter; clash now 0 mm³.

## Material Selection & FEA (chest mount)

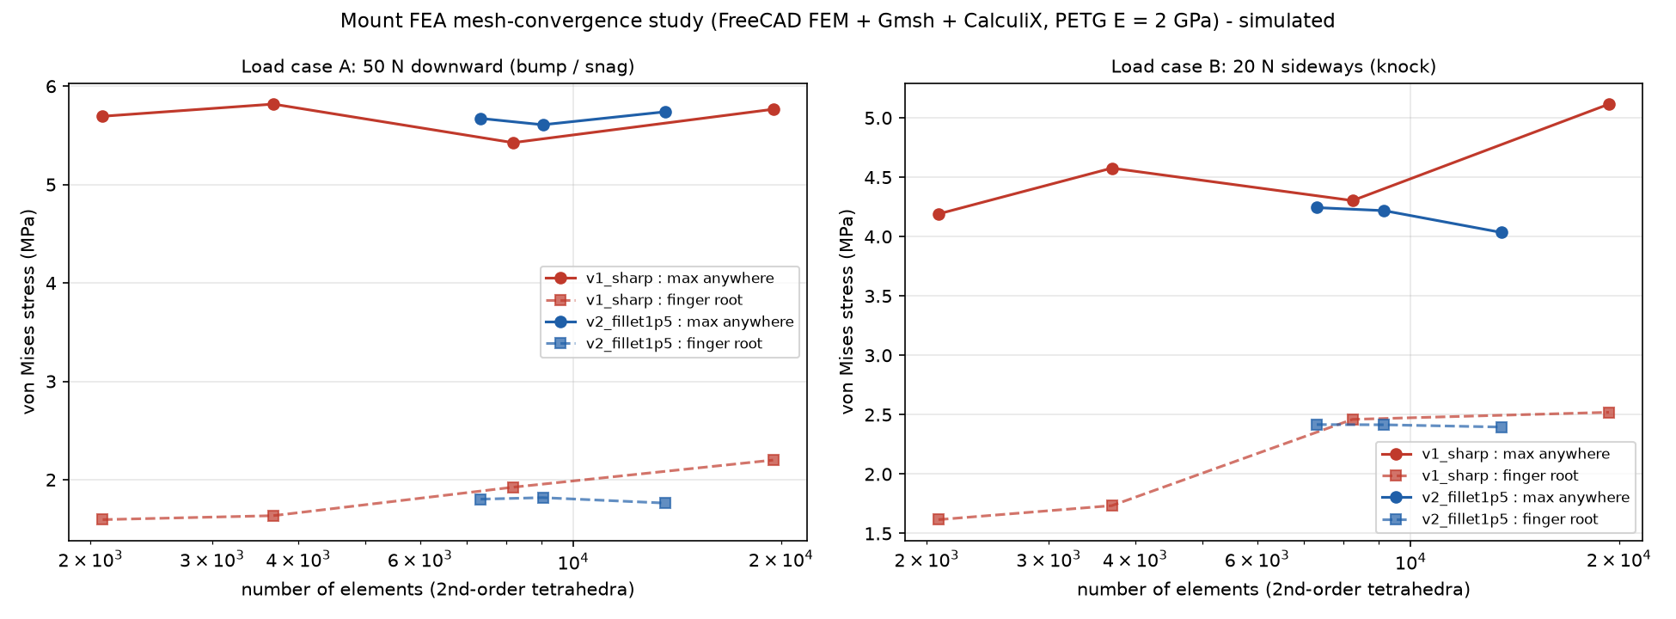
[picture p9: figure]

SIMULATED

Material | Tg / softening | Choice
PLA | ≈ 60 °C | No - softens in a car / summer sun
PETG | ≈ 80 °C | Yes - tough, easy to print
ASA | ≈ 100 °C, UV-stable | Stage 3 option outdoors

FreeCAD FEM + Gmsh + CalculiX
- Load A: 50 N down (0.3 kg × ~17 g bump); B: 20 N sideways
- PETG: E 2.0 GPa, ν 0.38, yield ≈ 50 MPa; required FoS ≥ 3
- Result: v2 worst FoS 8.7 (every run ≥ 8.6); max deflection 0.064 mm
- v1: root stress kept rising with mesh refinement → sharp-corner singularity
- v2: 1.5 mm root fillets → converged (≤ 3 % spread, 3 meshes); now in the CAD

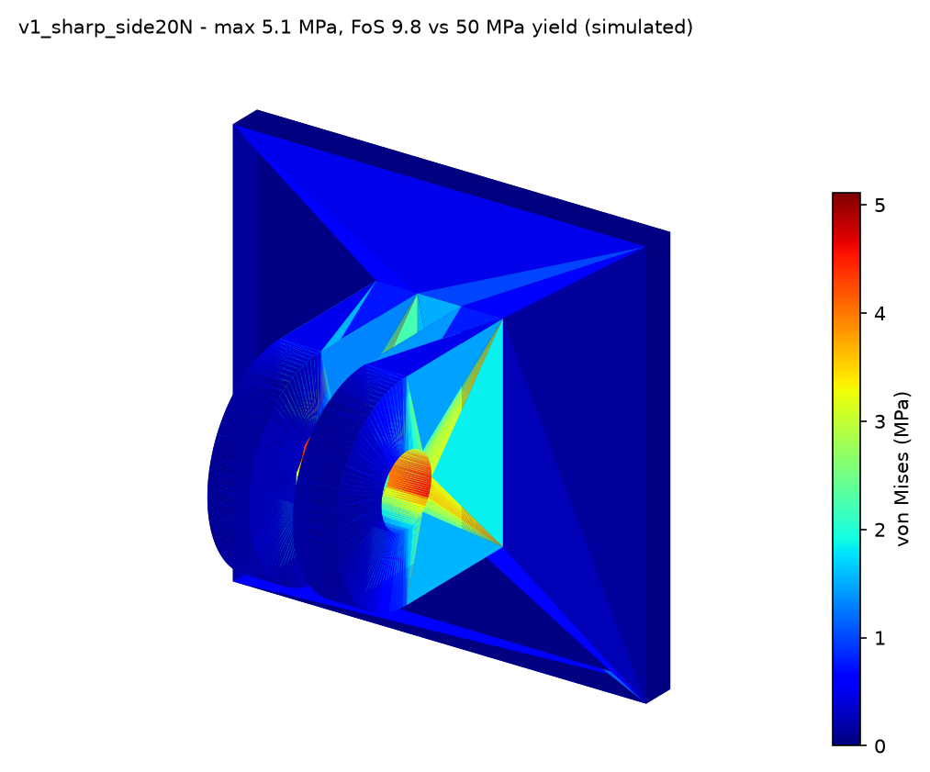
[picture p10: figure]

v1 sharp roots - 20 N side

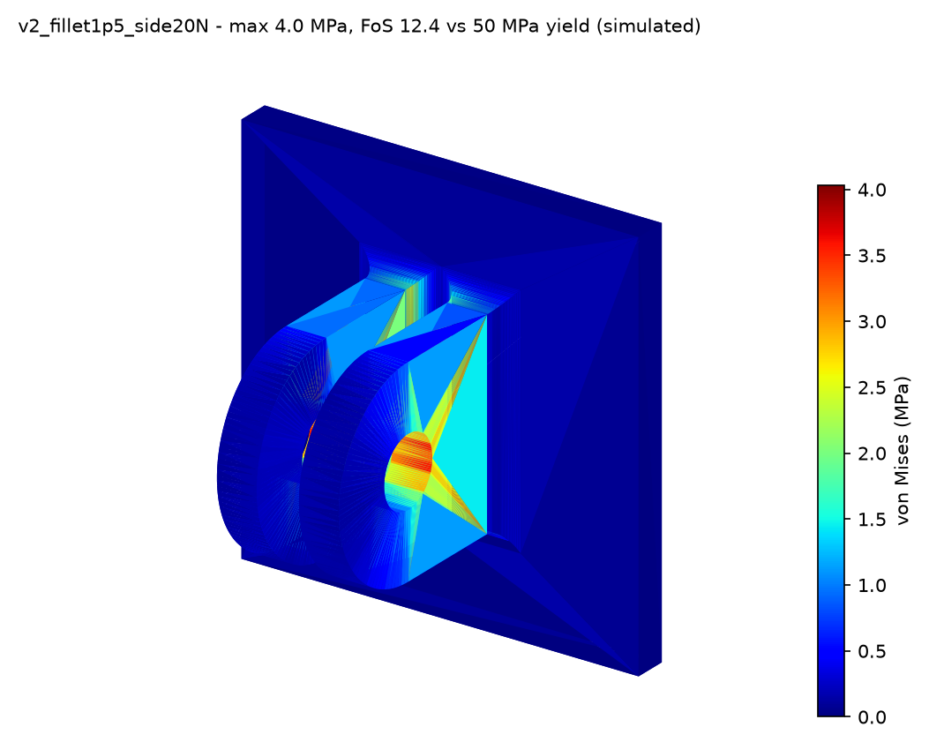
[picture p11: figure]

v2 1.5 mm fillets - 20 N side

Limitations: linear isotropic model (printed parts are anisotropic); finest v2 mesh failed to solve, so v2 uses 3 mesh levels; a printed-mount pull test is planned for Stage 3.

## Electronics - Schematic & Carrier PCB

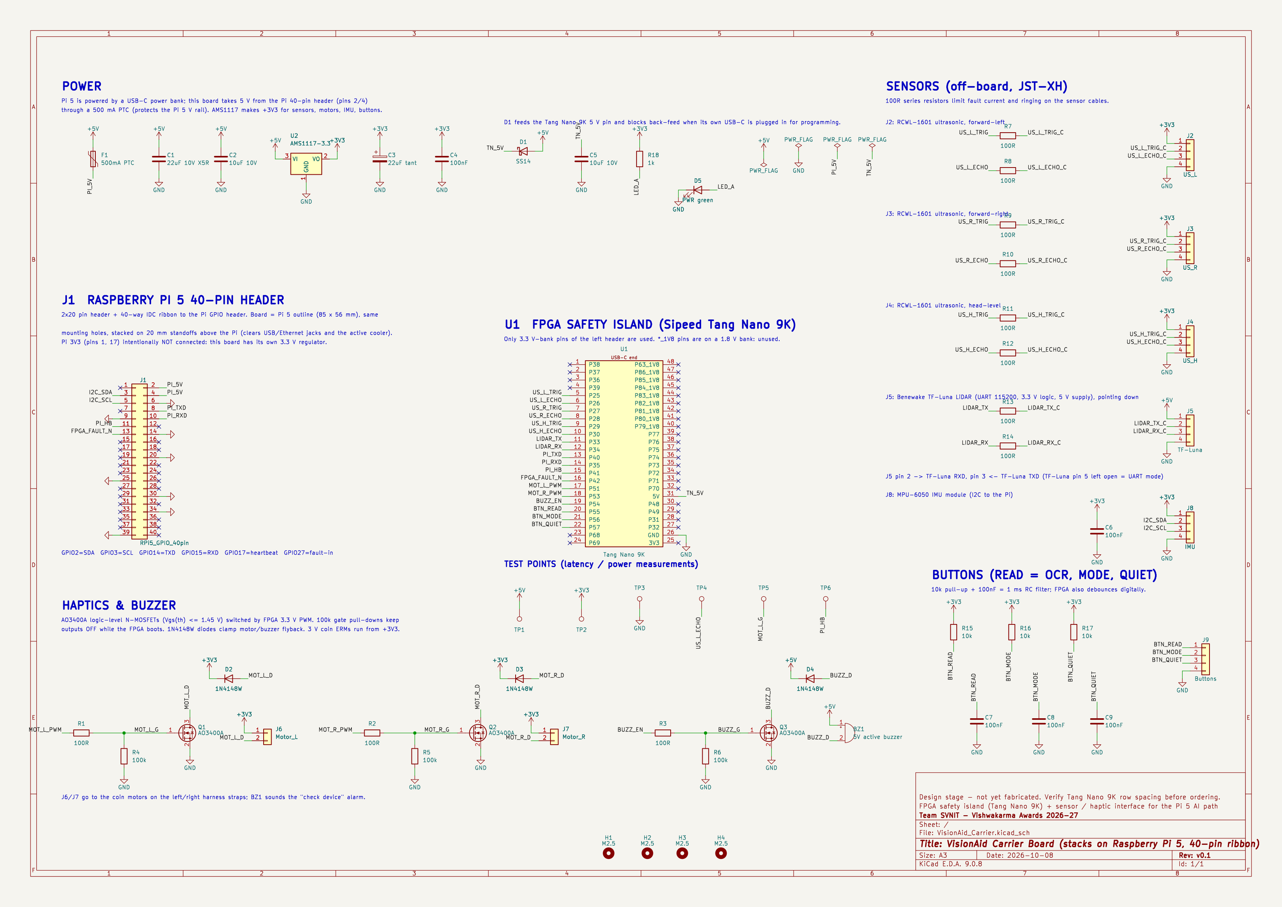
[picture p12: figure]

Carrier-board schematic (A3): power, Pi header, FPGA, sensors, haptics, buttons, test points

KICAD 9

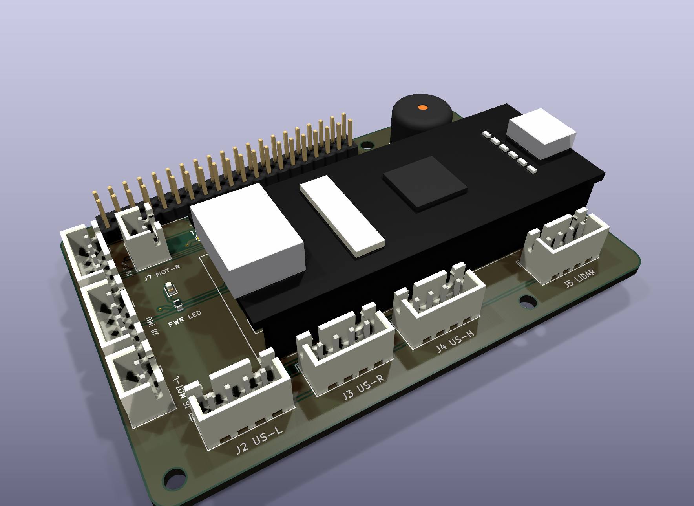
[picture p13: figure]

Power distribution & checks
- Power bank → Pi 5 → header 5 V → 500 mA PTC → +5 V
- +5 V → AMS1117 → +3V3 (sensors, motors, IMU)
- +5 V → SS14 → Tang Nano (blocks USB back-feed)
- Verified: ERC 0 · DRC 0 · unrouted 0 · parity 0

PCB: 85 × 56 mm, 2 layers, Pi 5 outline + mounting holes, 20 mm standoffs + 40-way ribbon; 3.3 V-bank FPGA pins only; MOSFET motor drivers with flyback diodes; Gerbers generated.

## Bill of Materials & Sourcing

Component | Part / specification | Qty | Source · origin · lead | ₹ (basis)
AI computer | Raspberry Pi 5 4 GB + active cooler | 1 | KSP Electronics · imported · out of stock | 15,050 (quote + est.)
FPGA | Sipeed Tang Nano 9K | 1 | Probots · imported · out of stock | 2,999 (quote)
Camera | Pi Camera Module 3 + cable | 1 | Thingbits · imported · in stock | 3,358 (quote + est.)
LiDAR | Benewake TF-Luna | 1 | Probots · imported · out of stock | 2,118 (quote)
Ultrasonic + IMU | RCWL-1601 × 4, MPU-6050 | 5 | Robu · local · 2-4 d | 800 (est.)
Feedback | Coin motors × 2, BT bone-conduction headset | 3 | Robu / Amazon.in · 2-5 d | 2,120 (est.)
Power | 10,000 mAh BIS power bank | 1 | local · 1-3 d | 1,200 (est.)
Carrier PCB | 2-layer fab ×5 + SMD parts + connectors + ribbon | 1 | LionCircuits (domestic) · 5-7 d | 3,250 (est.)
Mechanical | PETG, standoffs, inserts, harness, buttons | 1 | Robu / Amazon.in · 2-5 d | 2,350 (est.)
microSD | 64 GB A2 | 1 | local · 1-3 d | 700 (est.)
TOTAL | | | Grant ₹30,000 | 33,945

Budget - honest status
- Everything except the Pi 5 board: ₹19,445.
- Pi 5 4 GB on 9 Oct: ₹12,600-14,500, out of stock → ₹2,045-3,945 over the grant.
- Rule: Pi 5 must be ≤ ₹10,555 to fit; else re-quote or cover the gap from team funds.

Battery life (calculated, cited Pi 5 W)
- Pi 5: ≈ 3.0 W idle, ≈ 8.8 W full load (published); rest 1.34 W (est.)
- AI always on: 10.1 W → 3.1 h
- Event-triggered, ~50 % (assumed): 7.2 W → 4.3 h
- AI idle: 4.3 W → 7.2 h

Procurement status: nothing ordered in Stage 2. Quotes are live listings checked 9 Oct 2026; Pi 5, Tang Nano 9K and TF-Luna were out of stock that day - re-quote and order early. Itemised BOM: design/bom/VisionAid_BOM_Power.xlsx.

## FPGA Safety Island - Verification & Implementation

SIM + REAL P&R

Testbench check (Icarus Verilog) | Result
Distance 1500 / 2500 mm | 1499 / 2499 mm
Echo edge → motor ON | 136 ns wave; ≤ 214 ns bound
Frames to Pi (Verilog / Py) | 192 / 192 decoded, 0 bad
LiDAR drop-off | alert 22.3 ms after change
Pi heartbeat lost | AI-offline 666 ms; alerts on
Sensor unplugged | fault flag + FAULT_N low
Overall | ALL TESTS PASSED

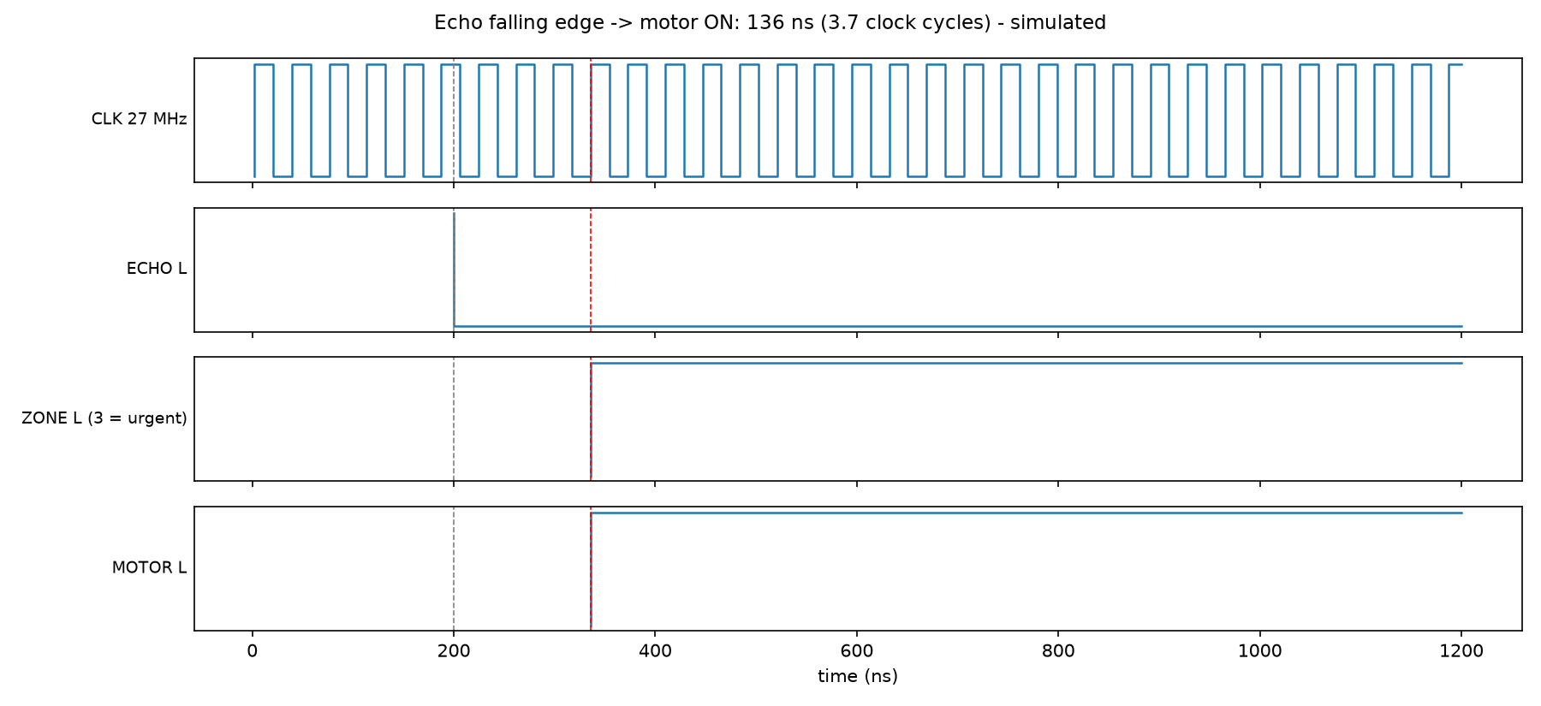
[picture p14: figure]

27 MHz | GW1NR-9 nextpnr | Zynq-7020 Vivado
LUTs | 1,512 / 8,640 (17 %) | 653 / 53,200 (1.2 %)
Flip-flops | 568 / 6,480 (8 %) | 580 / 106,400 (0.55 %)
ALU / DSP | 914 ALU (14 %) | 1 DSP (0.45 %)
Block RAM | 0 / 26 | 0 / 140
I/O | 26 / 276 | n/a (OOC run)
Timing | Fmax 67.9 MHz, met | WNS +30.2 ns, met

Plotted event: 136 ns from echo edge to motor ON (motor rises on the same clock as the zone change). The testbench monitor samples 2 clocks later, so its 214 ns is a conservative upper bound.

Cross-verified: the Verilog FPGA accepted a command built by our Python Pi code, and the Python decoder read every byte the FPGA sent - both sides of the link agree.

Routed results (GW1NR-9 bitstream built; Vivado out-of-context). No hardware yet.

## AI Path (Raspberry Pi software) - Proof of Concept

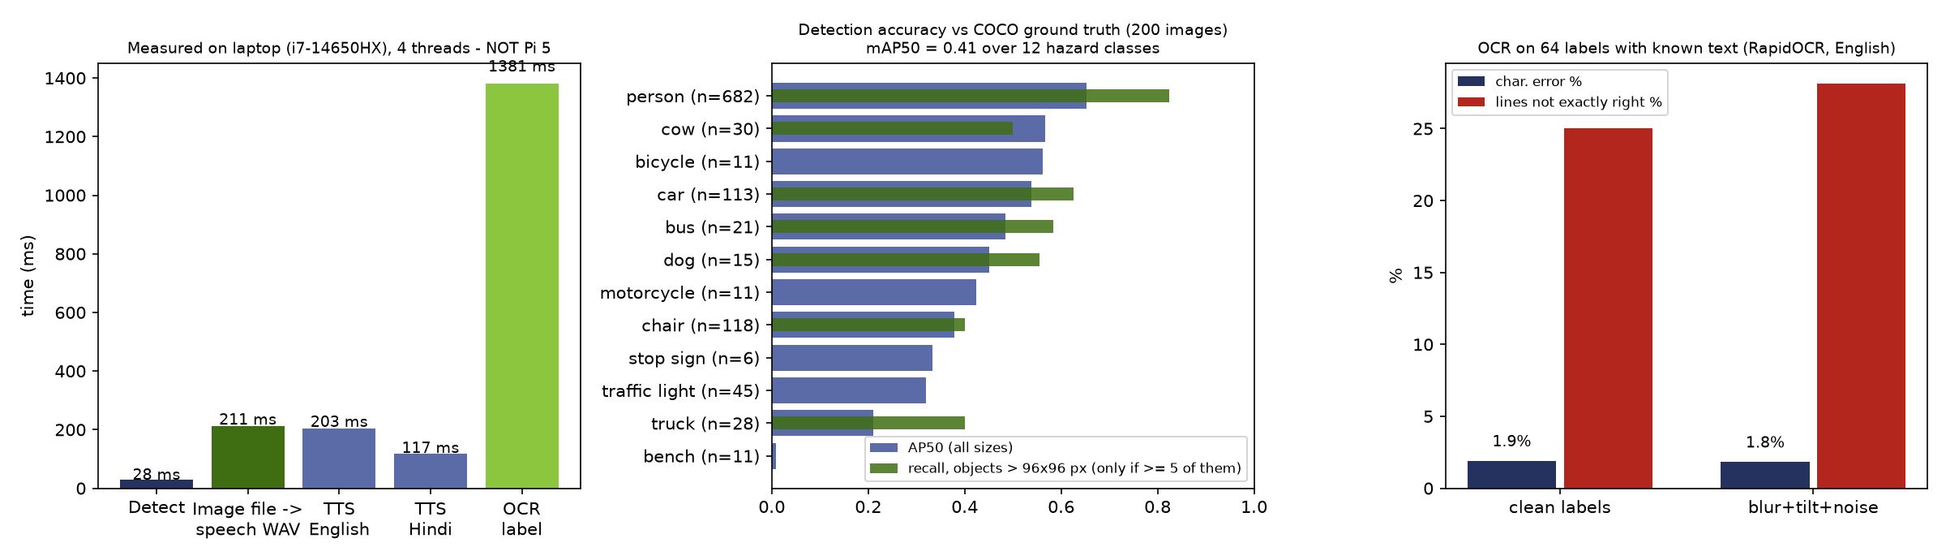
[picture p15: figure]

MEASURED · LAPTOP

What runs (same code for the Pi 5)
- YOLOv5n (ONNX) → hazard + side; RapidOCR; Piper TTS English + Hindi; alert manager; IMU floor baseline
- Event-triggered: AI runs only when the FPGA sees an obstacle < 3 m

Full-loop replay (FPGA sim bytes → speech)
- "Step down ahead. Stop." · "Check device: head sensor."
- "person, left, 1.6 metres" - WAV files in design/pi/results/replay

Honest scope: speeds measured on an i7 laptop (4 threads), NOT on a Pi 5; 211 ms excludes camera capture and audio playback. Accuracy is hardware-independent (COCO: 200 images vs human labels; OCR: 64 synthetic labels). Pi 5 timing in Stage 3.

## Model Training - Pothole Detector (fine-tuned)

TRAINED · HELD-OUT TEST


Our model on 16 held-out test images (boxes = its predictions, number = confidence)

Held-out test split (100 images, 269 potholes) | Result
Precision | 0.64
Recall | 0.30
mAP50 / mAP50-95 | 0.37 / 0.15
Speed, laptop CPU, 4 threads (not Pi 5) | 26 ms / image
Before fine-tuning (COCO model) | no pothole class at all

How it was trained
- YOLO11n, COCO-pretrained start, 100 epochs, RTX 5060 GPU, 7.7 min
- Public dataset, CC BY 4.0: 100 train / 100 valid / 100 test images
- Checked: no train-test image overlap (name + pixel hash, incl. flips)

Honest limits
- Finds ~3 in 10 potholes; ~2 in 3 detections are real
- Small set of mostly non-Indian road photos, taken from vehicle / hand height
- Stage 3: Indian, chest-height data from our own camera

Why it matters: the whole training pipeline (data checks → fine-tune → held-out test → ONNX for the Pi) works end to end; files in design/pi/training.

## Sensor Coverage & Drop-off Analysis

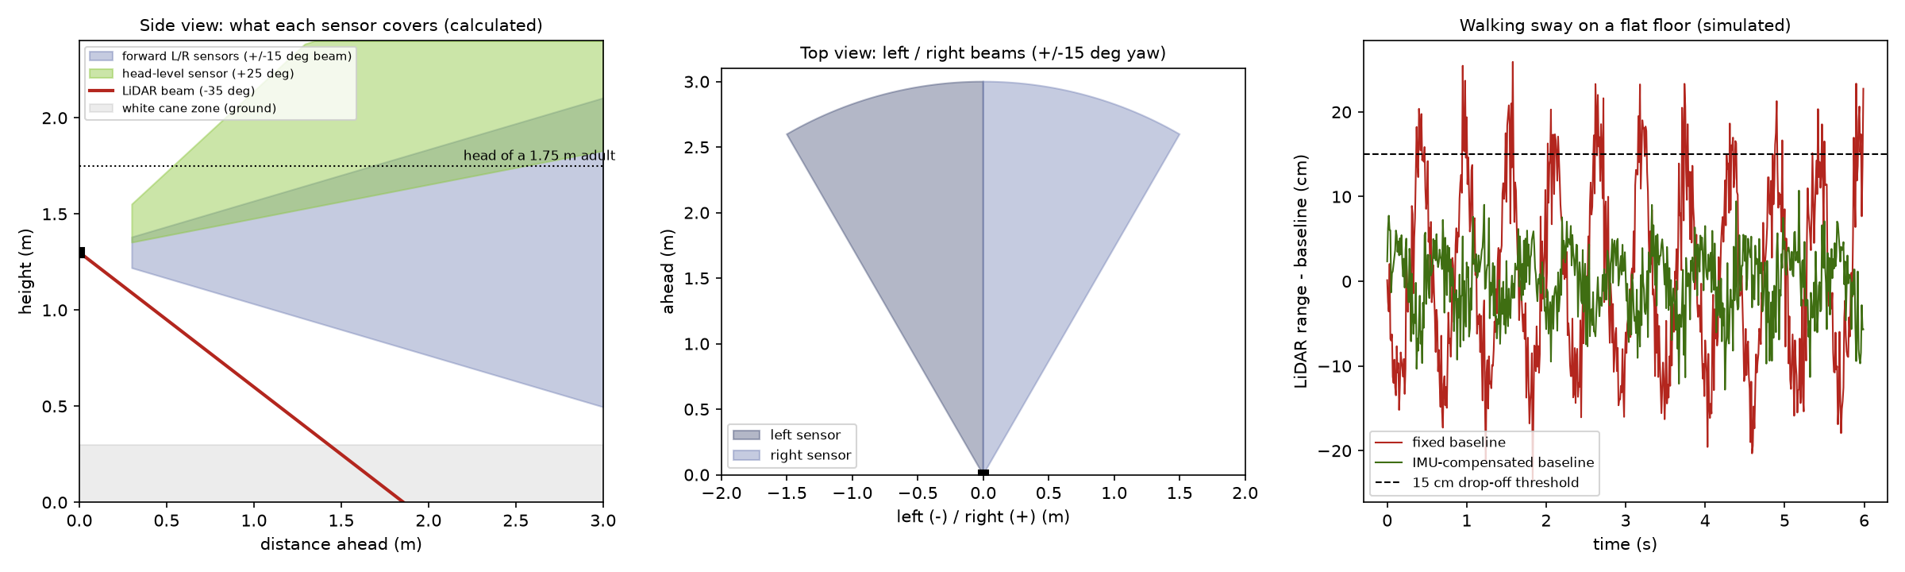
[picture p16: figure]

CALCULATED + SIMULATED

Drop-off: target met
LiDAR at −35° from 1.3 m sees a 15 cm step 1.86 m ahead (≈ 1.5 s at walking speed)

Found: walking sway
±3° chest sway → 25 false alarms in 20 s; IMU-corrected baseline → 0 (now in the Pi code)

Found: waist-height gap
Under 1 m ahead, 0.3-1.0 m height is not covered → tilt forward sensors −10° in CAD v2

Assumptions: 1.3 m pod height, 15° ultrasonic half-beam (datasheet class), ±3° sway at 1.8 Hz, 1 cm LiDAR noise - design/analysis/sensor_geometry.py.

## Your Maker Journey - Evidence

PHOTO TO ADD:
team member doing CAD / KiCad with SVNIT ID badge visible

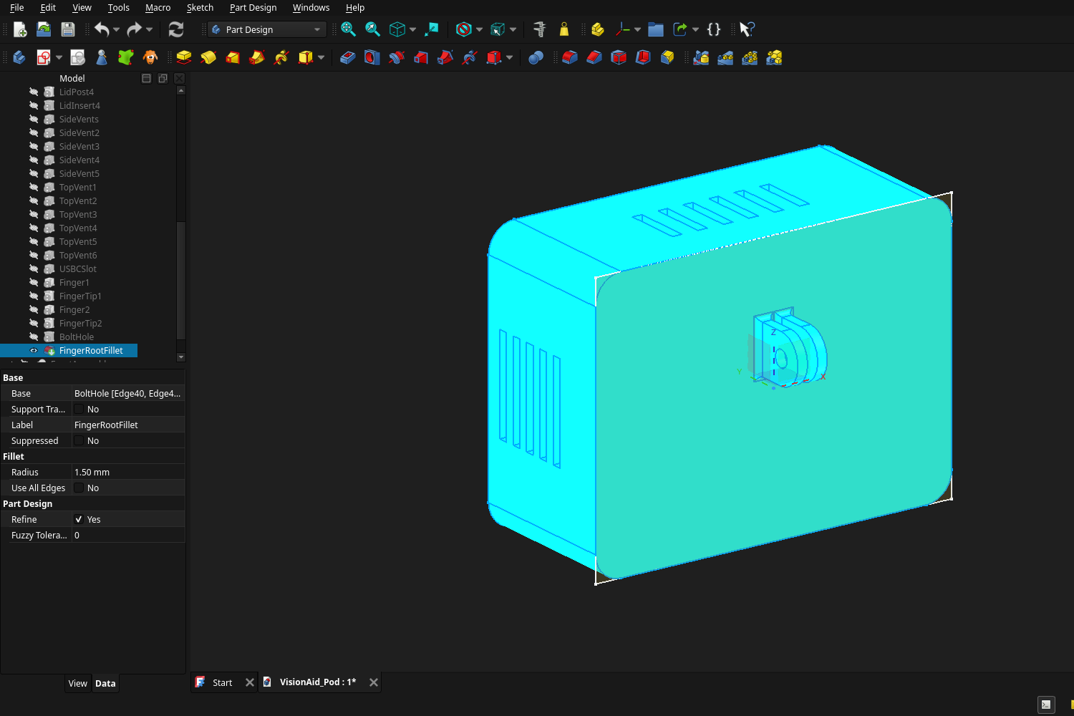
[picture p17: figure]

FreeCAD feature tree - FingerRootFillet R 1.5 mm

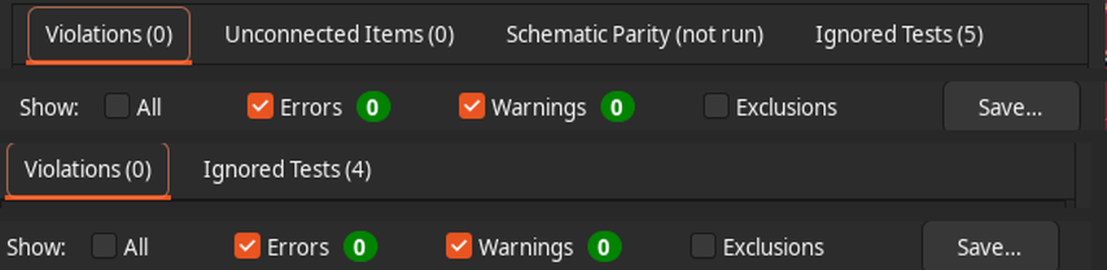
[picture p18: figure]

KiCad DRC: 0 violations, 0 unconnected · ERC: 0 errors, 0 warnings

Raw repository (native files)
github.com/silentaf/viswa_id1 - .FCStd, .step, .kicad_sch/.kicad_pcb, .v, .xlsx, timestamped commits

PHOTO TO ADD:
joint review with faculty guide / IIT Indore mentor

GTKWave: echo falls → distance 749 mm → zone 3 → left motor ON (simulation)

Stage 1 → 2: PYNQ-Z2 → Pi 5 + Tang Nano 9K; per-stage latency specs; LiDAR for drop-offs; FEA-driven fillet; CAD clash fix 44 → 48 mm (details on the next slide).

## Stage 1 → Stage 2 Engineering Iterations

Stage 1 said | Stage 2 decision | Why
PYNQ-Z2 does everything | Pi 5 (AI) + Tang Nano 9K FPGA (safety island) | 2 × A9 650 MHz vs 4 × A76 2.4 GHz for AI; fault isolation
"<10 ms" reflex, "<100 ms" on cover | Per-stage specs: echo → motor ≤ 1 ms | Echo from 3 m alone takes ≈ 17.5 ms - "<10 ms end-to-end" is impossible
Downward ultrasonic for drop-offs | Downward TF-Luna LiDAR (−35°) | Narrow beam gives a clean floor-distance signal
Wristband with 2 motors | L / R motors on the chest straps, wired | Two motors on one wrist are hard to tell apart; no radio in safety path
Custom bone-conduction driver | Bluetooth bone-conduction headset | Pi 5 has no analog audio; speech is the information channel
"< ₹5,500 BOM" | Prototype BOM ₹33,945 at 9 Oct quotes | Pi 5 + camera alone exceed ₹5,500
"250M+", "₹4-6 lakh" competitors | Cited 2020 data; SmartCane disclosed | Accuracy and honest public-search disclosure
10-15 pilot users | Stage 3, after ethics approval + O&M instructor | Honest scope for a design round

Found by our own analysis: FEA → 1.5 mm root fillets; CAD clash → shell 44 → 48 mm; sway simulation → IMU floor baseline; power analysis → event-triggered AI; tests → OCR word-order bug fixed.

## Safety & Hazard Mitigation

Failure mode | Hazard | Embedded fail-safe / mitigation
Ultrasonic stuck / unplugged | Missed obstacle | No-response detector (3 slots) → buzzer "check device" + FAULT_N (simulated)
Pi crash / hang | No object names / OCR | FPGA watchdog → "AI offline" chirp; alert path unaffected (simulated)
Bluetooth headset drops | No speech | Haptics carry all safety alerts; distinct cue
Walking sway / tilt | False drop-off alarms | IMU-corrected floor baseline: 25 → 0 false alarms (simulated)
Pi 5 overheats in pod | Throttling, slow AI | Active cooler + vents in CAD; thermal test in Stage 3
Carrier short circuit | Pi 5 V rail damage | 500 mA PTC fuse on the header supply
Battery fire | Burns | BIS-certified power bank only - no loose Li-ion cells
Alert fatigue | User ignores alerts | Zone hysteresis + quiet mode (silences "info" only)

Standards considered in the design (not certified)
- IEC 62368-1 / IS 13252 - ICT equipment safety
- IEC 62133-2 / IS 16046 - Li-ion (via BIS power bank)
- IEC 60529 - IP54 target for the pod
- ISO 10993-5/-10 - skin-contact materials (harness)
- ISO 9999 - assistive-product classification
- WPC / ETA - only pre-certified radio modules

Design principle: the cane stays the primary aid - VisionAid only adds warnings, and its alert path is independent of the AI computer.

## Roadmap - 4-Month Fabrication Plan

Nov 2026

Dec 2026

Jan 2027

Feb 2027

- Order parts + carrier PCB (LionCircuits)
- FPGA + sensor bring-up on the bench
- Range, latency (logic analyser at TP4/TP5), power tests

- PCB assembly; Pi software integration
- Print + fit enclosure; thermal test in pod
- India-class dataset (auto-rickshaw, cow, pothole, drain)

- Ethics approval (institute ethics committee)
- Supervised trials: sighted blindfolded first
- Then blind volunteers with an O&M instructor

- Fix top issues from trials
- Re-run all Stage 2 tests on hardware
- Field-test-ready unit for Stage 3

Stage 3 commitment
A wearable, battery-powered VisionAid prototype ready for supervised functional field testing, with every Stage 2 target (range, alert latency, drop-off distance, runtime, mass) measured on hardware.

Research extension: RISC-V soft core (PicoRV32) on the Tang Nano + a tiny spiking neural network to classify sensor patterns (stairs / wall / person) at very low power - once real sensor data exists.

## Technical Challenges & Risks

Ultrasonic crosstalk vs update rate
Three sensors firing together hear each other. Sequencing fixes it but limits each direction to one ping per 99 ms (simulated).

Enclosure clash found in CAD
With the Tang Nano 3D model added, the module clashed with the lid by 182 mm³ - 171 mm³ of it the HDMI connector (CAD interference check).

Weight over target
Enclosure plastic alone ≈ 156 g if solid (CAD volume); with Pi 5 and sensors the pod likely exceeds 250 g.

Budget over the grant
At 9 Oct quotes the BOM is ₹33,945 - ₹3,945 over the ₹30k grant; Pi 5, Tang Nano and TF-Luna were out of stock.

Battery vs always-on AI
With the AI always running, the calculated runtime is 3.1 h - below the 4 h target (cited Pi 5 power).

Sway false alarms + coverage gap
Simulation: 25 false drop-off alarms in 20 s with a fixed floor baseline; waist-height gap under 1 m ahead.

Source of each risk: our own design files - CAD interference report, FEA study, BOM workbook, FPGA simulation - not assumptions copied from elsewhere.

## Potential Solutions & Risk Mitigation

Risk | Mitigation / backup
Crosstalk vs rate | Keep sequencing; Stage 3 option: coded pings to fire in parallel
Enclosure clash | Done: shell depth 44 → 48 mm (one parameter); interference now 0 mm³
Weight | v2: 2.0 mm walls + 20 % infill, merge housings, Pi Compute Module later
Budget | Pi 5 must be ≤ ₹10,555 to fit; re-quote at order time, else team funds cover the gap
Battery | Done in code: event-triggered AI → 4.3 h (calc., ~50 % AI duty assumed); measure on hardware
Sway / gap | Done: IMU floor baseline (0 false alarms, sim.); gap: forward sensors −10° in CAD v2
Mount corners | Done: 1.5 mm root fillets (FEA v2 converged, FoS ≥ 8.7)
Pi failure / heat | FPGA watchdog + independent alert path (simulated); cooler + vents, thermal test

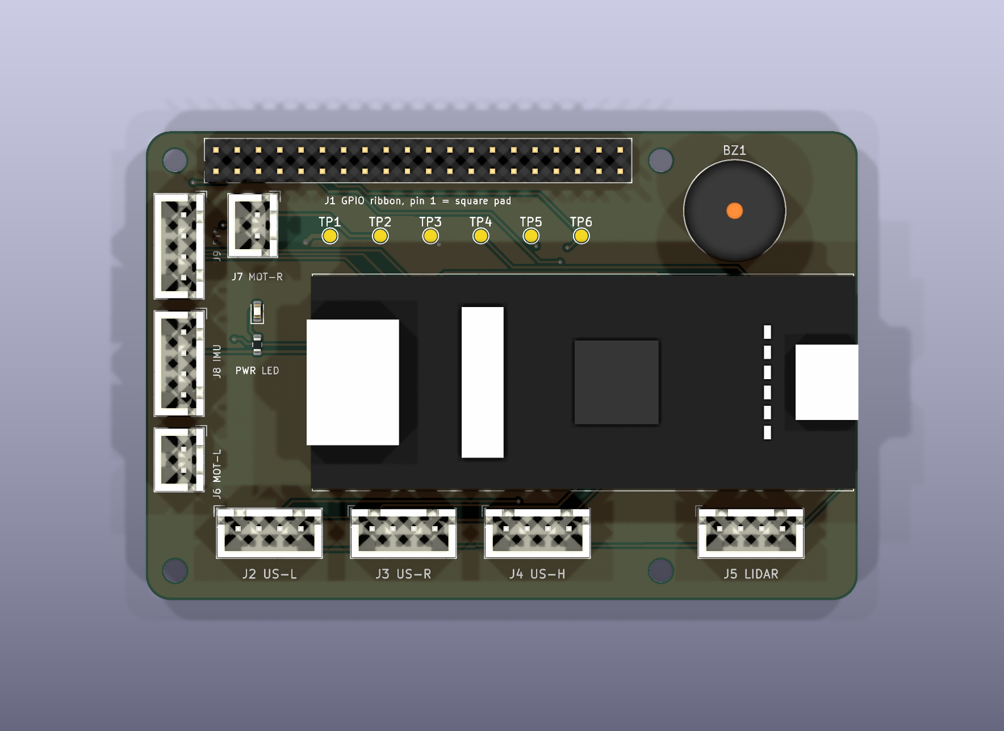
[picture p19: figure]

Carrier PCB with the Tang Nano 9K model (KiCad)

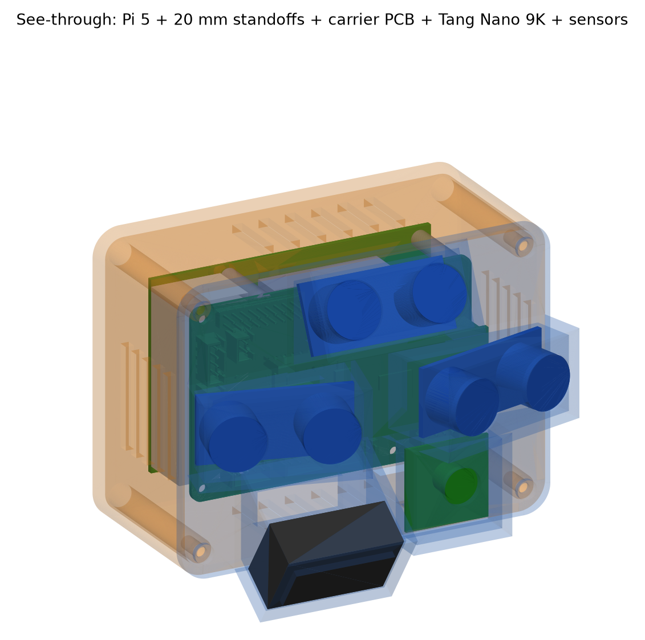
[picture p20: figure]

Status: "Done" items are already in the design files; the rest are planned and will be verified on hardware in Stage 3.

## References & Sources

References
- Bourne R. et al., Trends in prevalence of blindness and vision impairment, Lancet Global Health 9(2):e130-e143, 2021.
- National Blindness & Visual Impairment Survey India 2015-19, AIIMS / MoHFW (indiavisionatlasnpcb.aiims.edu).
- Manduchi R., Kurniawan S., Mobility-related accidents experienced by people with visual impairment, Insight 4(2), 2011 (tech. report UCSC-SOE-10-24; 307 respondents).
- SmartCane - IIT Delhi / Assistech: ₹3,500 (Snapdeal launch, 2016; entrepreneur.com, electronicsforu.com).
- OrCam MyEye 3 Pro US$4,250 (nelowvision.com); Envision Glasses US$1,899 / 3,499 (shop.letsenvision.com) - checked 9 Oct 2026.
- Sipeed Tang Nano 9K wiki and pin map; Benewake TF-Luna datasheet; Raspberry Pi 5 / Camera Module 3 product briefs.
- Raspberry Pi 5 power (≈ 3.0 W idle, ≈ 8.8 W full load): raspberry.tips power comparison, 2026. Part prices: kspelectronics.in, electronifyindia.com, probots.co.in, thingbits.in (9 Oct 2026).
- COCO val2017 (cocodataset.org); YOLOv5n, YOLO11n (Ultralytics); RapidOCR / PP-OCR; Piper TTS (rhasspy). Pothole data: Roboflow Universe "Potholes Detection" (project-ssayl), CC BY 4.0, via Hugging Face Ryukijano/Pothole-detection-Yolov8.
- Tools: KiCad 9, FreeCAD + CalculiX + Gmsh, Icarus Verilog, GTKWave, Yosys, nextpnr + Apicula, Vivado 2026.1, FreeRouting.

Image sources
- All diagrams, renders, plots and screenshots in this deck are our own, generated from the project files in github.com/silentaf/viswa_id1 (one exception below):
- CAD renders - design/cad (FreeCAD model)
- PCB / schematic - design/electronics (KiCad)
- FEA plots - design/cad/outputs/fea
- Waveforms - design/fpga (testbench); AI / analysis charts - design/pi, design/analysis
- Screenshots - docs/screenshots
- Exception: the road photos on the pothole slide are from the public dataset above (CC BY 4.0); only the boxes are our model's output.
- Logos: Vishwakarma Awards / Maker Bhavan Foundation (official template).

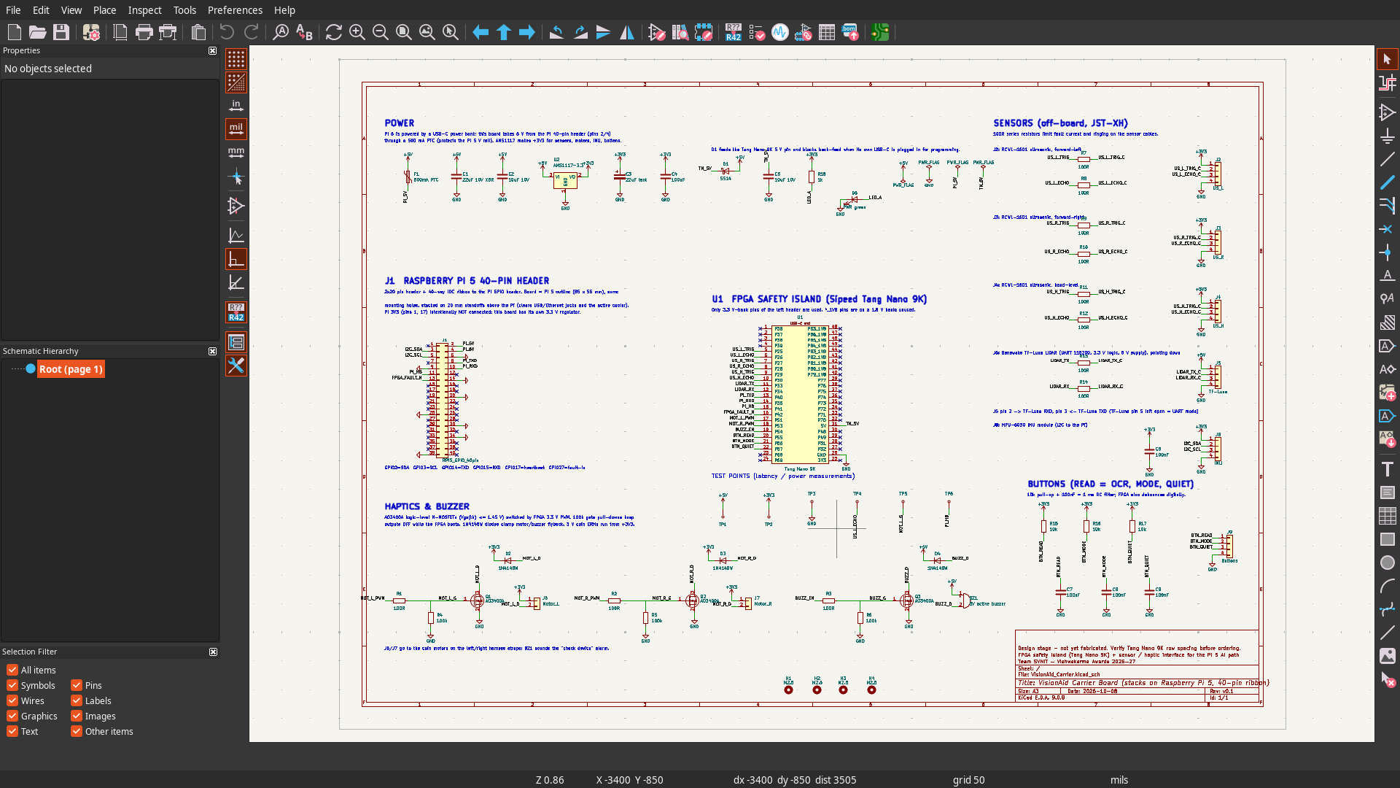
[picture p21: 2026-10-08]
docs/screenshots/kicad_04_schematic.png

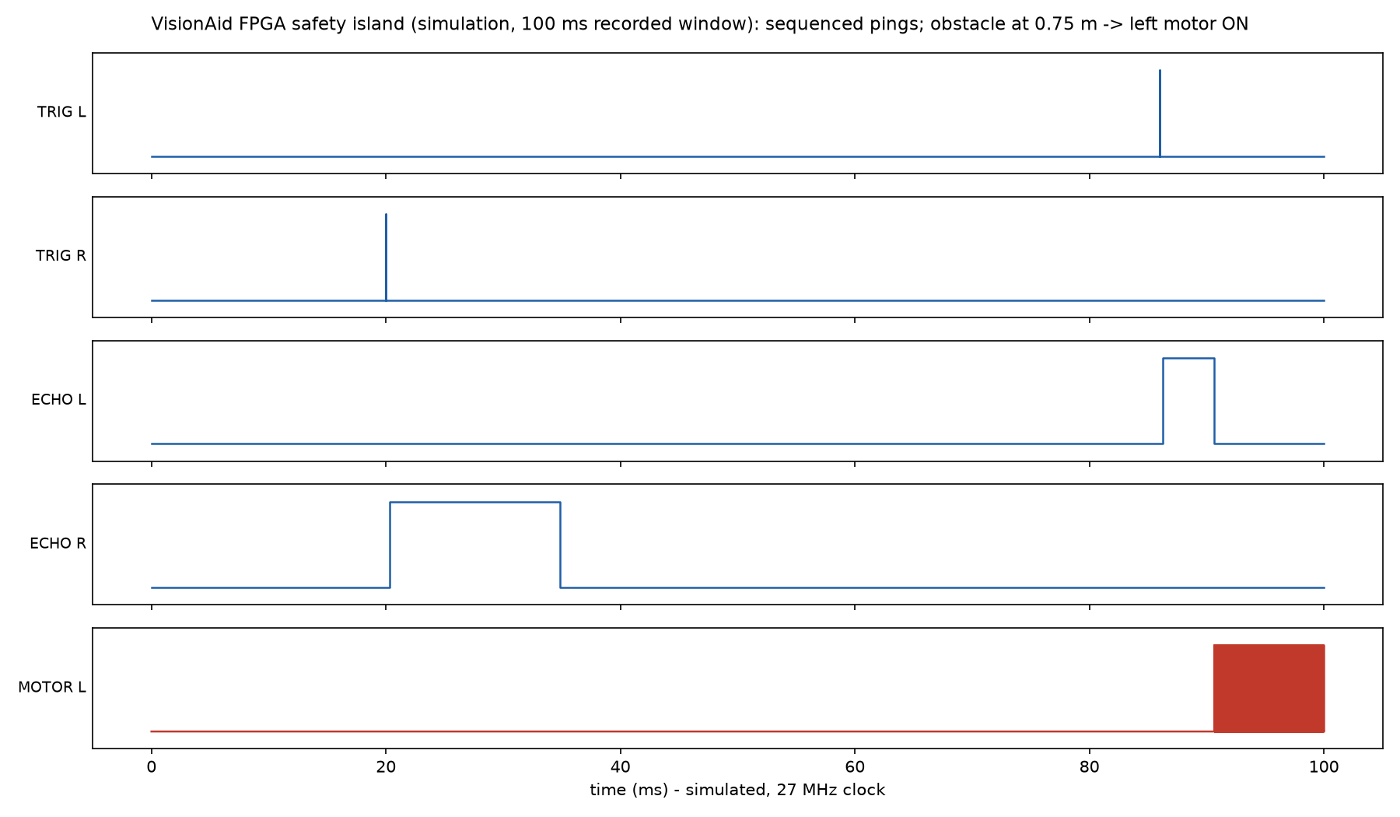
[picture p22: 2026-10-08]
ppt/assets/waveform_overview.png

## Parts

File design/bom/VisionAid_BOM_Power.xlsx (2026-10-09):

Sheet: Prototype BOM
VisionAid prototype BOM (Stage 2 design). Quote = live listing checked 9 Oct 2026; Estimate = verify before ordering.
Group | Item | Part / specification | Qty | Unit price (INR) | Line total (INR) | Price basis | Source | Origin | Lead time
Compute | AI computer | Raspberry Pi 5, 4 GB | 1 | 14500 |  | Quote | kspelectronics.in INR 14,500 incl. GST (out of stock, 9 Oct); electronifyindia.com INR 12,600 (sold out) | Imported, local distributor | stock-dependent
Compute | Active cooler | Raspberry Pi 5 Active Cooler | 1 | 550 |  | Estimate | Thingbits / Robocraze | Imported, local distributor | 2-4 days
Compute | Storage | 64 GB microSD, A2 | 1 | 700 |  | Estimate | Local / Amazon.in | Local | 1-3 days
Compute | FPGA safety island | Sipeed Tang Nano 9K (GW1NR-9) | 1 | 2999 |  | Quote | probots.co.in INR 2,999 incl. GST (out of stock, 9 Oct) | Imported, local distributor | stock-dependent
Sensing | Camera | Raspberry Pi Camera Module 3 (standard, autofocus) | 1 | 3158 |  | Quote | thingbits.in INR 3,157.68 incl. GST (in stock, 9 Oct) | Imported, local distributor | 2-4 days
Sensing | Camera cable | Pi 5 camera FFC 22-15 pin, 300 mm | 1 | 200 |  | Estimate | Robu / Thingbits | Imported, local distributor | 2-4 days
Sensing | Ultrasonic sensor | RCWL-1601 (3.3 V, HC-SR04 pin-out), incl. 1 spare | 4 | 150 |  | Estimate | Robu / Probots | Imported, local distributor | 2-4 days
Sensing | Drop-off LiDAR | Benewake TF-Luna (0.2-8 m, UART) | 1 | 2118 |  | Quote | probots.co.in INR 2,118 incl. GST (out of stock, 9 Oct) | Imported, local distributor | stock-dependent
Sensing | IMU | MPU-6050 (GY-521) module | 1 | 200 |  | Estimate | Robu | Local | 2-4 days
Feedback | Haptic motors | 10 mm coin ERM, 3 V | 2 | 60 |  | Estimate | Robu | Local | 2-4 days
Feedback | Audio | Bluetooth bone-conduction headset (budget) | 1 | 2000 |  | Estimate | Amazon.in | Imported | 2-5 days
Power | Battery | 10,000 mAh USB-C power bank, BIS-certified | 1 | 1200 |  | Estimate | Amazon.in / local | Local brand | 1-3 days
Carrier PCB | PCB fabrication | 2-layer FR-4 85 x 56 mm, 5 pcs (this design) | 1 | 2000 |  | Estimate | LionCircuits (Bengaluru) | Domestic fab | 5-7 days
Carrier PCB | SMD parts | AMS1117, AO3400A x3, SS14, 1N4148W x3, R/C/LED, PTC (see KiCad BOM) | 1 | 500 |  | Estimate | Robu / Probots | Local | 2-4 days
Carrier PCB | Connectors | JST-XH sockets + housings + crimps, 2x20 header, 2x 1x24 sockets, buzzer | 1 | 600 |  | Estimate | Robu | Local | 2-4 days
Carrier PCB | Ribbon | 40-way IDC ribbon, 2 sockets, ~10 cm | 1 | 150 |  | Estimate | Robu | Local | 2-4 days
Mechanical | Filament | PETG 1 kg (enclosure ~156 g if printed solid: 123 cm3 x 1.27 g/cm3) | 1 | 1200 |  | Estimate | Robu / Amazon.in | Local | 2-4 days
Mechanical | Fasteners | M2.5 x 20 mm standoffs x4, M3 heat-set inserts, M2.5/M3 screws | 1 | 400 |  | Estimate | Robu | Local | 2-4 days
Mechanical | Chest harness | GoPro-style chest harness + M5 thumb screw | 1 | 600 |  | Estimate | Amazon.in | Imported | 2-5 days
Mechanical | Buttons | 3 x 12 mm tactile buttons with caps (READ / MODE / QUIET) | 1 | 150 |  | Estimate | Robu | Local | 2-4 days
 | TOTAL
 | Quoted items subtotal
 | Grant |  |  |  | 30000
 | Reserve (grant - total)
 | BUDGET RULE | Everything except the Pi 5 board costs INR 19,445, so the Pi 5 4 GB must cost <= INR 10,555 to stay inside the INR 30,000 grant. On 9 Oct 2026 the checked listings were INR 12,600-14,500 and out of stock, i.e. INR 2,045-3,945 over. Rule: re-quote at order time; if no Pi 5 4 GB <= INR 10,555, cover the gap from team funds or move to a cheaper board (re-quote and re-test in Stage 3).

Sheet: Power budget
VisionAid power budget - DESIGN ESTIMATE (not measured). Verify in Stage 3 with a USB-C power meter.
Block | Rail | Current (mA) | Voltage (V) | Power (W) | Basis
Raspberry Pi 5, event-triggered AI | 5 V |  | 5 | 5.9 | Cited 3.0 W idle / 8.8 W full load (raspberry.tips 2026), AI busy ~50 % (assumption) -> 5.9 W; measure in Stage 3
Camera Module 3 | Pi |  | 3.3 | 0.25 | Assumption
Tang Nano 9K (FPGA + on-board USB bridge) | 5 V | 80 | 5 |  | Assumption
TF-Luna LiDAR | 5 V | 70 | 5 |  | Datasheet: average current <= 70 mA
3 x RCWL-1601 ultrasonic | 3.3 V | 9 | 3.3 |  | Assumption (~3 mA each)
2 x coin motors (30 % activity) | 3.3 V | 50 | 3.3 |  | Assumption (~80 mA each when on)
MPU-6050 IMU | 3.3 V | 4 | 3.3 |  | Datasheet-level estimate
AMS1117 loss (5 V -> 3.3 V, ~65 mA avg) | 5 V |  |  | 0.11 | (5 - 3.3) V x 65 mA
Buzzer, LEDs (rare) | 5 V | 5 | 5 |  | Assumption
Total average power (W)
Power bank energy (Wh): 10,000 mAh x 3.7 V |  |  |  | 37
Boost / cable efficiency (assumption) |  |  |  | 0.85
Estimated runtime (h)
Target |  |  |  | >= 4 h

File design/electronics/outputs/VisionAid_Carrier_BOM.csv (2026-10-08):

Refs | Value | Footprint | MPN | Qty
BZ1 | 5V active buzzer | Buzzer_Beeper:Buzzer_12x9.5RM7.6 | 12 mm 5 V active buzzer | 1
C1 | 22uF 10V X5R | Capacitor_SMD:C_1206_3216Metric |  | 1
C2,C5 | 10uF 10V | Capacitor_SMD:C_0805_2012Metric |  | 2
C3 | 22uF tant | Capacitor_Tantalum_SMD:CP_EIA-3528-21_Kemet-B |  | 1
C4,C6,C7,C8,C9 | 100nF | Capacitor_SMD:C_0603_1608Metric |  | 5
D1 | SS14 | Diode_SMD:D_SMA | SS14 | 1
D2,D3,D4 | 1N4148W | Diode_SMD:D_SOD-123 | 1N4148W | 3
D5 | PWR green | LED_SMD:LED_0603_1608Metric |  | 1
F1 | 500mA PTC | Fuse:Fuse_1206_3216Metric | 1206L050 / equivalent | 1
J1 | RPi5_GPIO_40pin | Connector_PinHeader_2.54mm:PinHeader_2x20_P2.54mm_Vertical |  | 1
J2 | US_L | Connector_JST:JST_XH_B4B-XH-A_1x04_P2.50mm_Vertical | JST B4B-XH-A | 1
J3 | US_R | Connector_JST:JST_XH_B4B-XH-A_1x04_P2.50mm_Vertical | JST B4B-XH-A | 1
J4 | US_H | Connector_JST:JST_XH_B4B-XH-A_1x04_P2.50mm_Vertical | JST B4B-XH-A | 1
J5 | TF-Luna | Connector_JST:JST_XH_B4B-XH-A_1x04_P2.50mm_Vertical | JST B4B-XH-A | 1
J6 | Motor_L | Connector_JST:JST_XH_B2B-XH-A_1x02_P2.50mm_Vertical | JST B2B-XH-A | 1
J7 | Motor_R | Connector_JST:JST_XH_B2B-XH-A_1x02_P2.50mm_Vertical | JST B2B-XH-A | 1
J8 | IMU | Connector_JST:JST_XH_B4B-XH-A_1x04_P2.50mm_Vertical | JST B4B-XH-A | 1
J9 | Buttons | Connector_JST:JST_XH_B4B-XH-A_1x04_P2.50mm_Vertical | JST B4B-XH-A | 1
Q1,Q2,Q3 | AO3400A | Package_TO_SOT_SMD:SOT-23 | AO3400A | 3
R1,R2,R3,R7,R8,R9,R10,R11,R12,R13,R14 | 100R | Resistor_SMD:R_0603_1608Metric |  | 11
R4,R5,R6 | 100k | Resistor_SMD:R_0603_1608Metric |  | 3
R15,R16,R17 | 10k | Resistor_SMD:R_0603_1608Metric |  | 3
R18 | 1k | Resistor_SMD:R_0603_1608Metric |  | 1
U1 | Tang Nano 9K | VisionAid:TangNano9K_Module | Sipeed Tang Nano 9K | 1
U2 | AMS1117-3.3 | Package_TO_SOT_SMD:SOT-223-3_TabPin2 | AMS1117-3.3 | 1

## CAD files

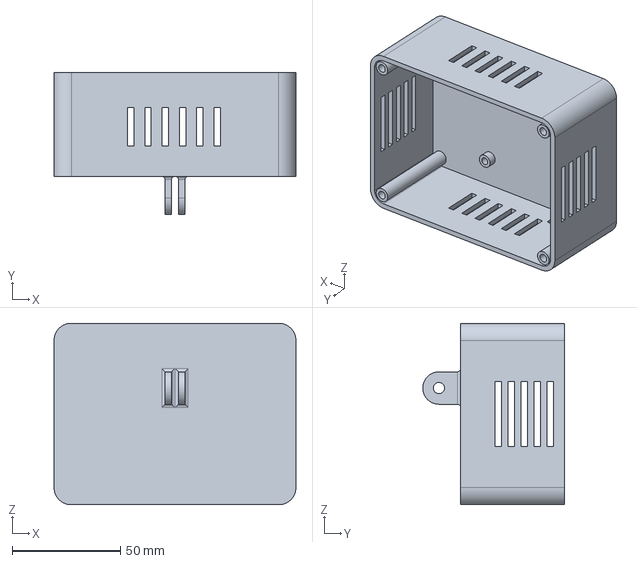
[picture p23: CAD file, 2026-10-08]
design/cad/outputs/BaseShell.step
112.0 x 65.5 x 84.0 mm

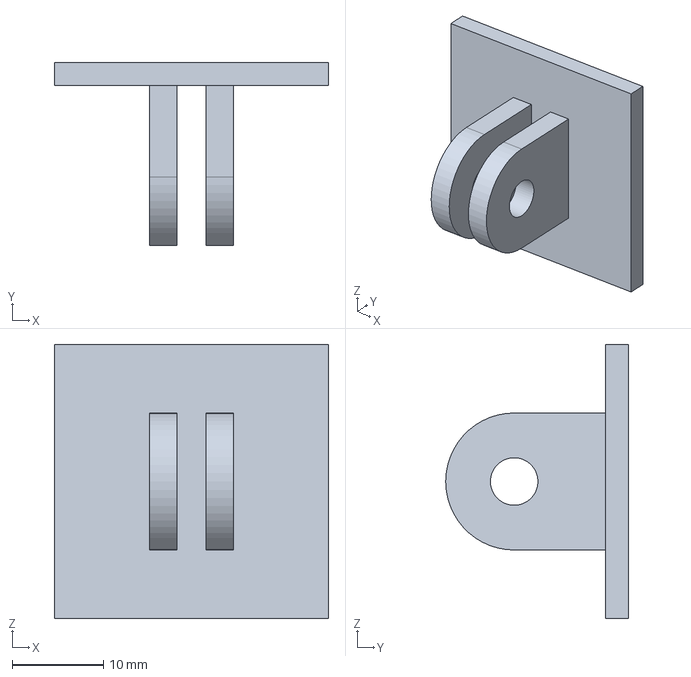
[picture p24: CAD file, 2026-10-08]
design/cad/outputs/fea/mount_v1_sharp.step
30.0 x 20.0 x 30.0 mm

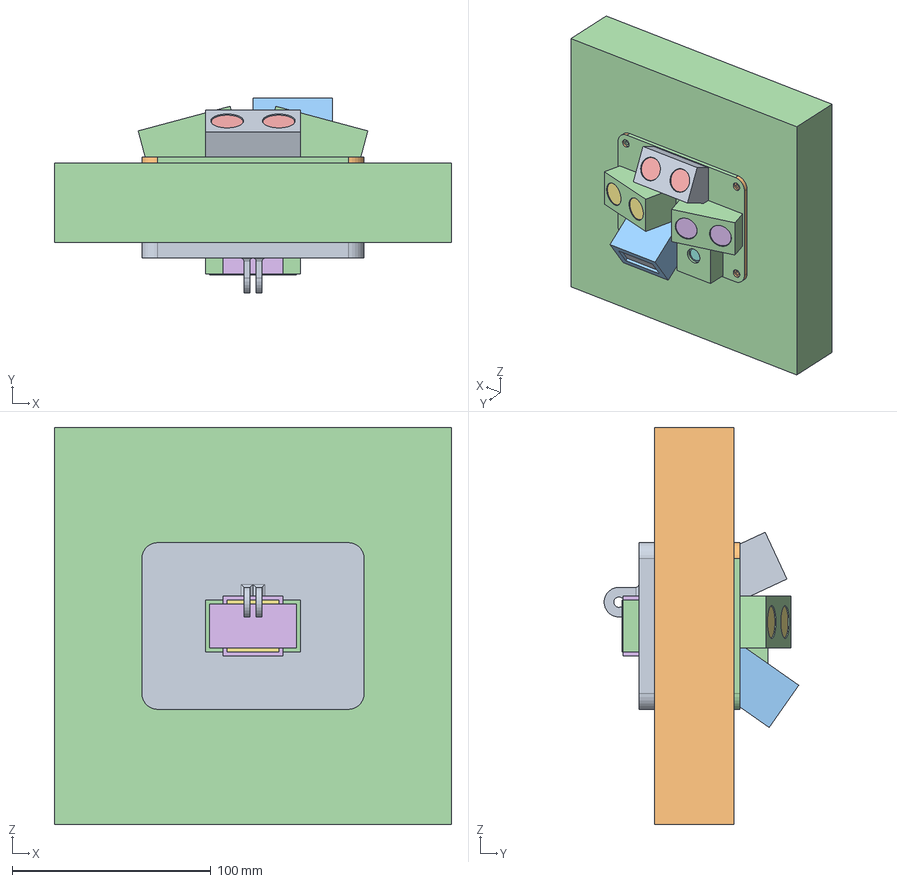
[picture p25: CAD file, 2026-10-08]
design/cad/VisionAid_Pod.FCStd
200.0 x 98.0 x 200.0 mm
BaseShell
FrontLid
Head_Outer
Head_Cavity
Head_Shell
Head_Hole1
Head_Hole2
Head_Openings
HeadHousing
Head_Clip
HeadHousingFinal
Left_Outer
Left_Cavity
Left_Shell
Left_Hole1
Left_Hole2
Left_Openings
LeftHousing
Left_Clip
LeftHousingFinal
Right_Outer
Right_Cavity
Right_Shell
Right_Hole1
Right_Hole2
Right_Openings
RightHousing
Right_Clip
RightHousingFinal
Camera_Outer
Camera_Cavity
Camera_Shell
Camera_Hole1
CameraHousing
Camera_Clip
CameraHousingFinal
Lidar_Outer
Lidar_Cavity
Lidar_Shell
Lidar_Hole1
LidarHousing
Lidar_Clip
LidarHousingFinal
FrontAssembly
RPi5_PCB
RPi5_ActiveCooler
RPi5_USB_Ethernet
CarrierPCB_from_KiCad
Standoff1
Standoff2
Standoff3
Standoff4
US_Head_RCWL1601
US_Left_RCWL1601
US_Right_RCWL1601
Camera_Module3
TFLuna_LiDAR

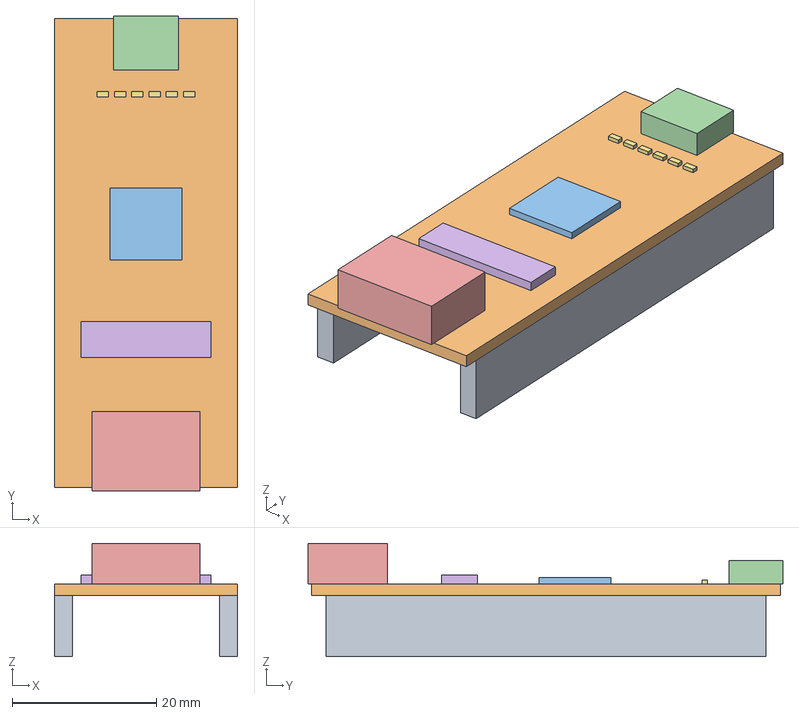
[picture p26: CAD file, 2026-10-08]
design/electronics/3d/TangNano9K_Module.step
25.4 x 65.8 x 15.7 mm
Socket1
Socket3
ModulePCB
FPGA_QFN88
USB_C
HDMI
LCD_FPC
LED0
LED1
LED2
LED3
LED4
LED5

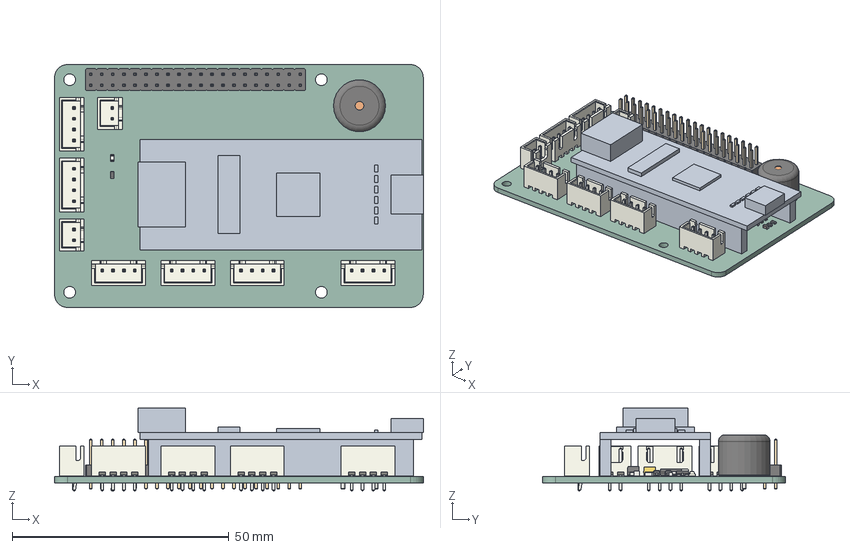
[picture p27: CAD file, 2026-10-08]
design/electronics/outputs/VisionAid_Carrier.step
85.0 x 56.0 x 19.1 mm
SOT-23 x 3
D_SOD-123 x 3
C_0603_1608Metric x 5
JST_XH_B4B-XH-A_1x04_P2.50mm_Vertical x 6
R_0603_1608Metric x 18
LED_0603_1608Metric
Buzzer_12x9.5RM7.6
Socket1
Socket3
ModulePCB
FPGA_QFN88
USB_C
HDMI
LCD_FPC
LED0
LED1
LED2
LED3
LED4
LED5
JST_XH_B2B-XH-A_1x02_P2.50mm_Vertical x 2
PinHeader_2x20_P2.54mm_Vertical
C_1206_3216Metric
C_0805_2012Metric x 2
CP_EIA-3528-21_Kemet-B
D_SMA
Fuse_1206_3216Metric
SOT-223
VisionAid_Carrier_PCB

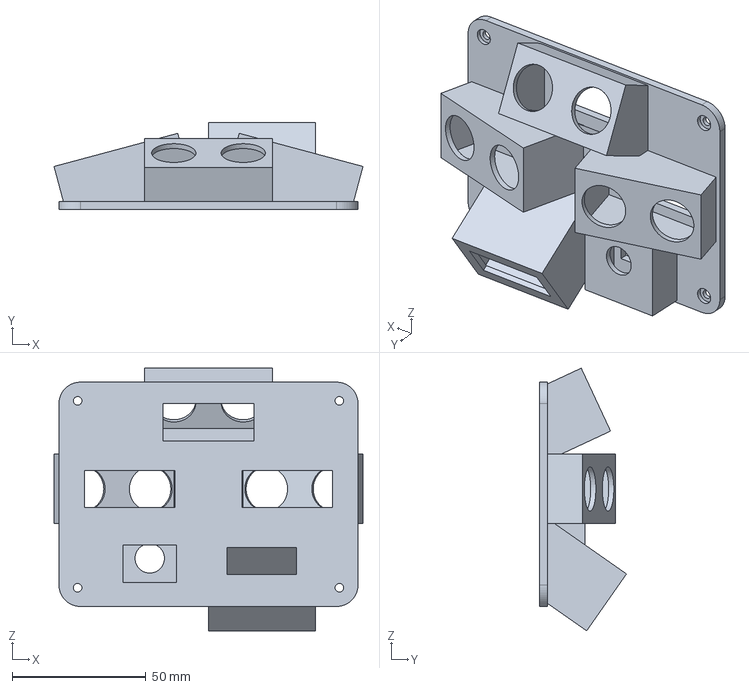
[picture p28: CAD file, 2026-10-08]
design/cad/outputs/FrontLid_with_housings.step
115.7 x 32.6 x 98.4 mm

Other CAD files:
design/cad/outputs/fea/mount_v2_fillet1p5.step
design/cad/outputs/BaseShell.stl
design/cad/outputs/FrontLid_with_housings.stl

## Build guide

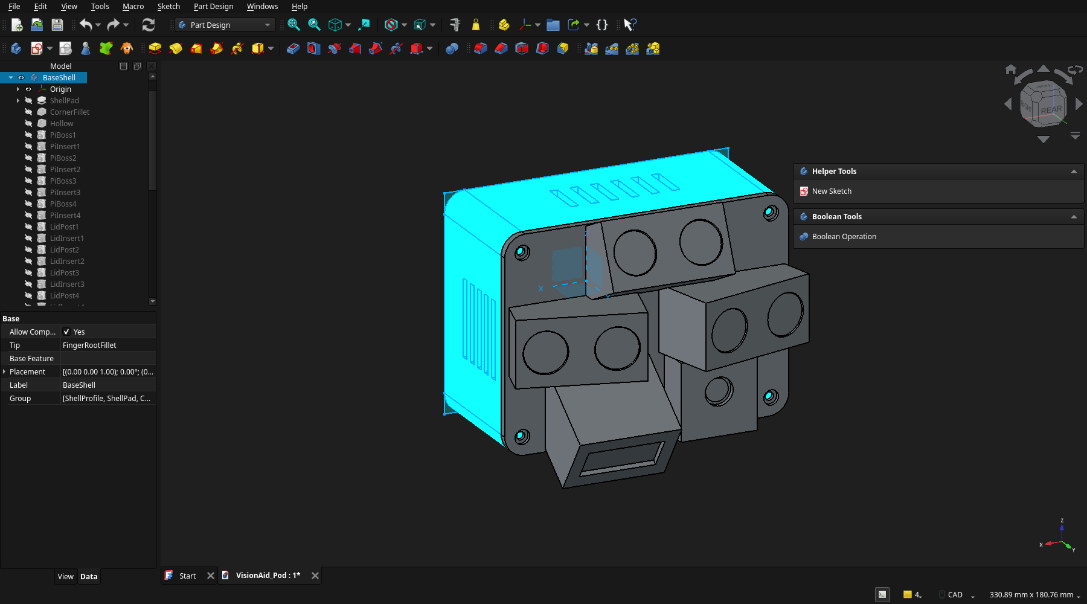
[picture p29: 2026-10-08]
docs/screenshots/freecad_02_assembly_iso.png

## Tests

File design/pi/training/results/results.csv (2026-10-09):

epoch | time | train/box_loss | train/cls_loss | train/dfl_loss | metrics/precision(B) | metrics/recall(B) | metrics/mAP50(B) | metrics/mAP50-95(B) | val/box_loss | val/cls_loss | val/dfl_loss | lr/pg0 | lr/pg1 | lr/pg2
1 | 27.6688 | 2.21075 | 3.42854 | 2.00676 | 0.0035 | 0.36713 | 0.00345 | 0.00121 | 2.05614 | 3.87011 | 2.00655 | 0.000571429 | 0.000571429 | 0.000571429
2 | 31.9448 | 2.19693 | 3.39816 | 2.04778 | 0.0033 | 0.34615 | 0.00369 | 0.00087 | 2.89513 | 4.61967 | 2.72487 | 0.00122584 | 0.00122584 | 0.00122584
3 | 36.6227 | 2.30648 | 3.09341 | 1.98724 | 0.0035 | 0.36713 | 0.00218 | 0.00055 | 2.69539 | 4.37664 | 3.54015 | 0.00186705 | 0.00186705 | 0.00186705
4 | 40.9583 | 2.22911 | 2.8817 | 1.93426 | 0.00157 | 0.16434 | 0.00056 | 0.00011 | 3.10211 | 4.71542 | 4.1196 | 0.0019406 | 0.0019406 | 0.0019406
5 | 45.135 | 2.27024 | 2.768 | 2.02708 | 0.00087 | 0.09091 | 0.00012 | 2e-05 | 3.8597 | 5.60073 | 14.4127 | 0.0019208 | 0.0019208 | 0.0019208
6 | 49.1328 | 2.19607 | 2.61469 | 1.96861 | 0.00246 | 0.05944 | 0.00031 | 5e-05 | 4.32064 | 86.7312 | 91.8936 | 0.001901 | 0.001901 | 0.001901
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

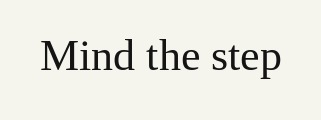
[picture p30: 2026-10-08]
design/pi/test_data/ocr/ocr_58.jpg

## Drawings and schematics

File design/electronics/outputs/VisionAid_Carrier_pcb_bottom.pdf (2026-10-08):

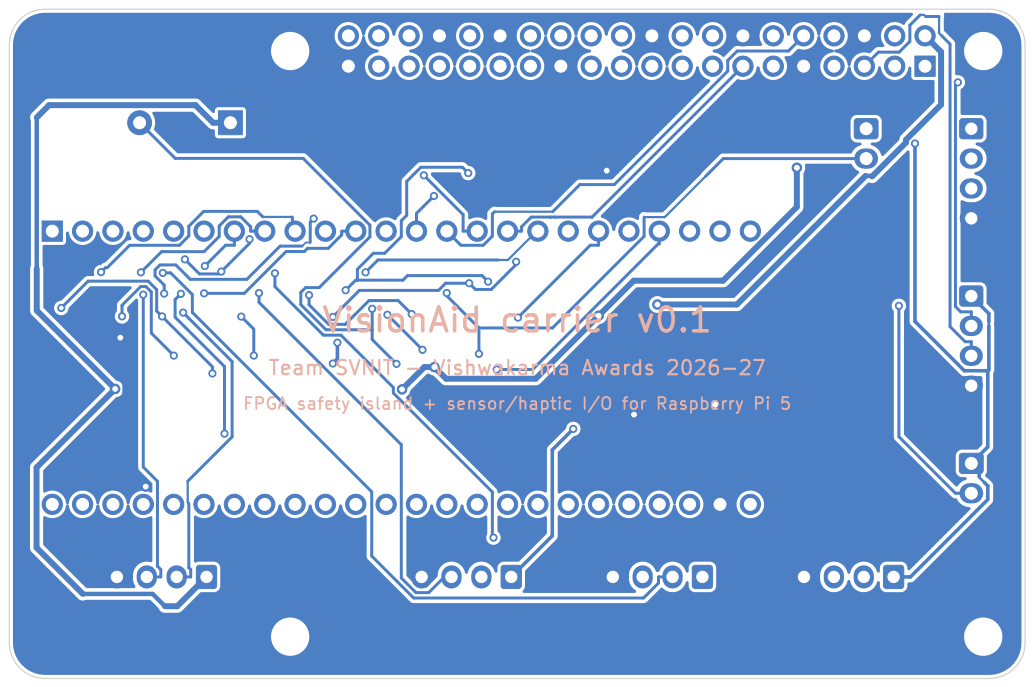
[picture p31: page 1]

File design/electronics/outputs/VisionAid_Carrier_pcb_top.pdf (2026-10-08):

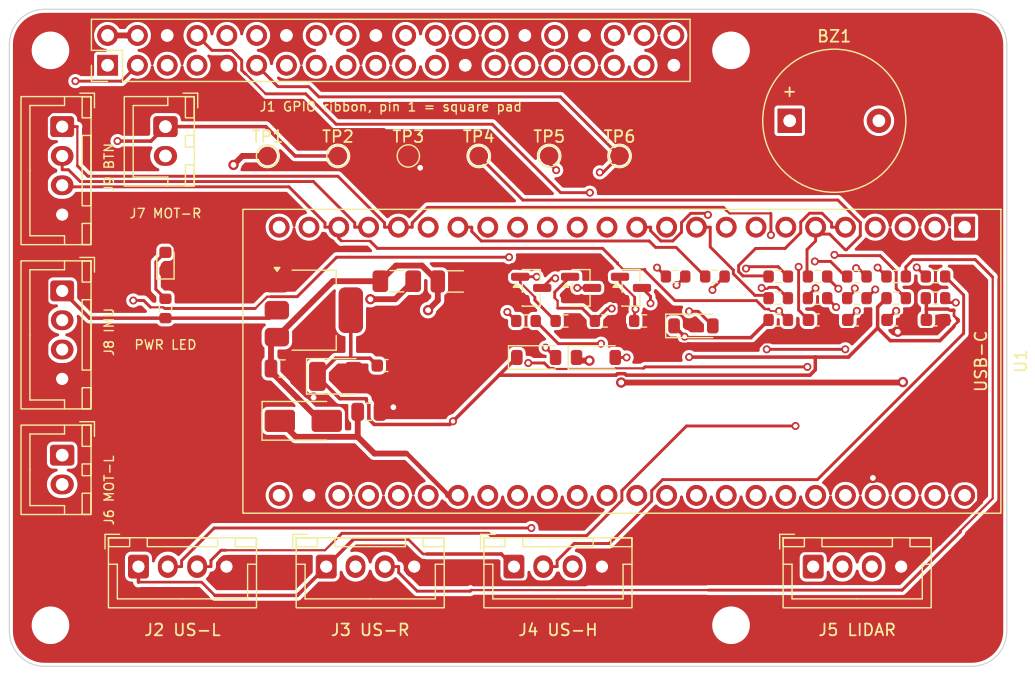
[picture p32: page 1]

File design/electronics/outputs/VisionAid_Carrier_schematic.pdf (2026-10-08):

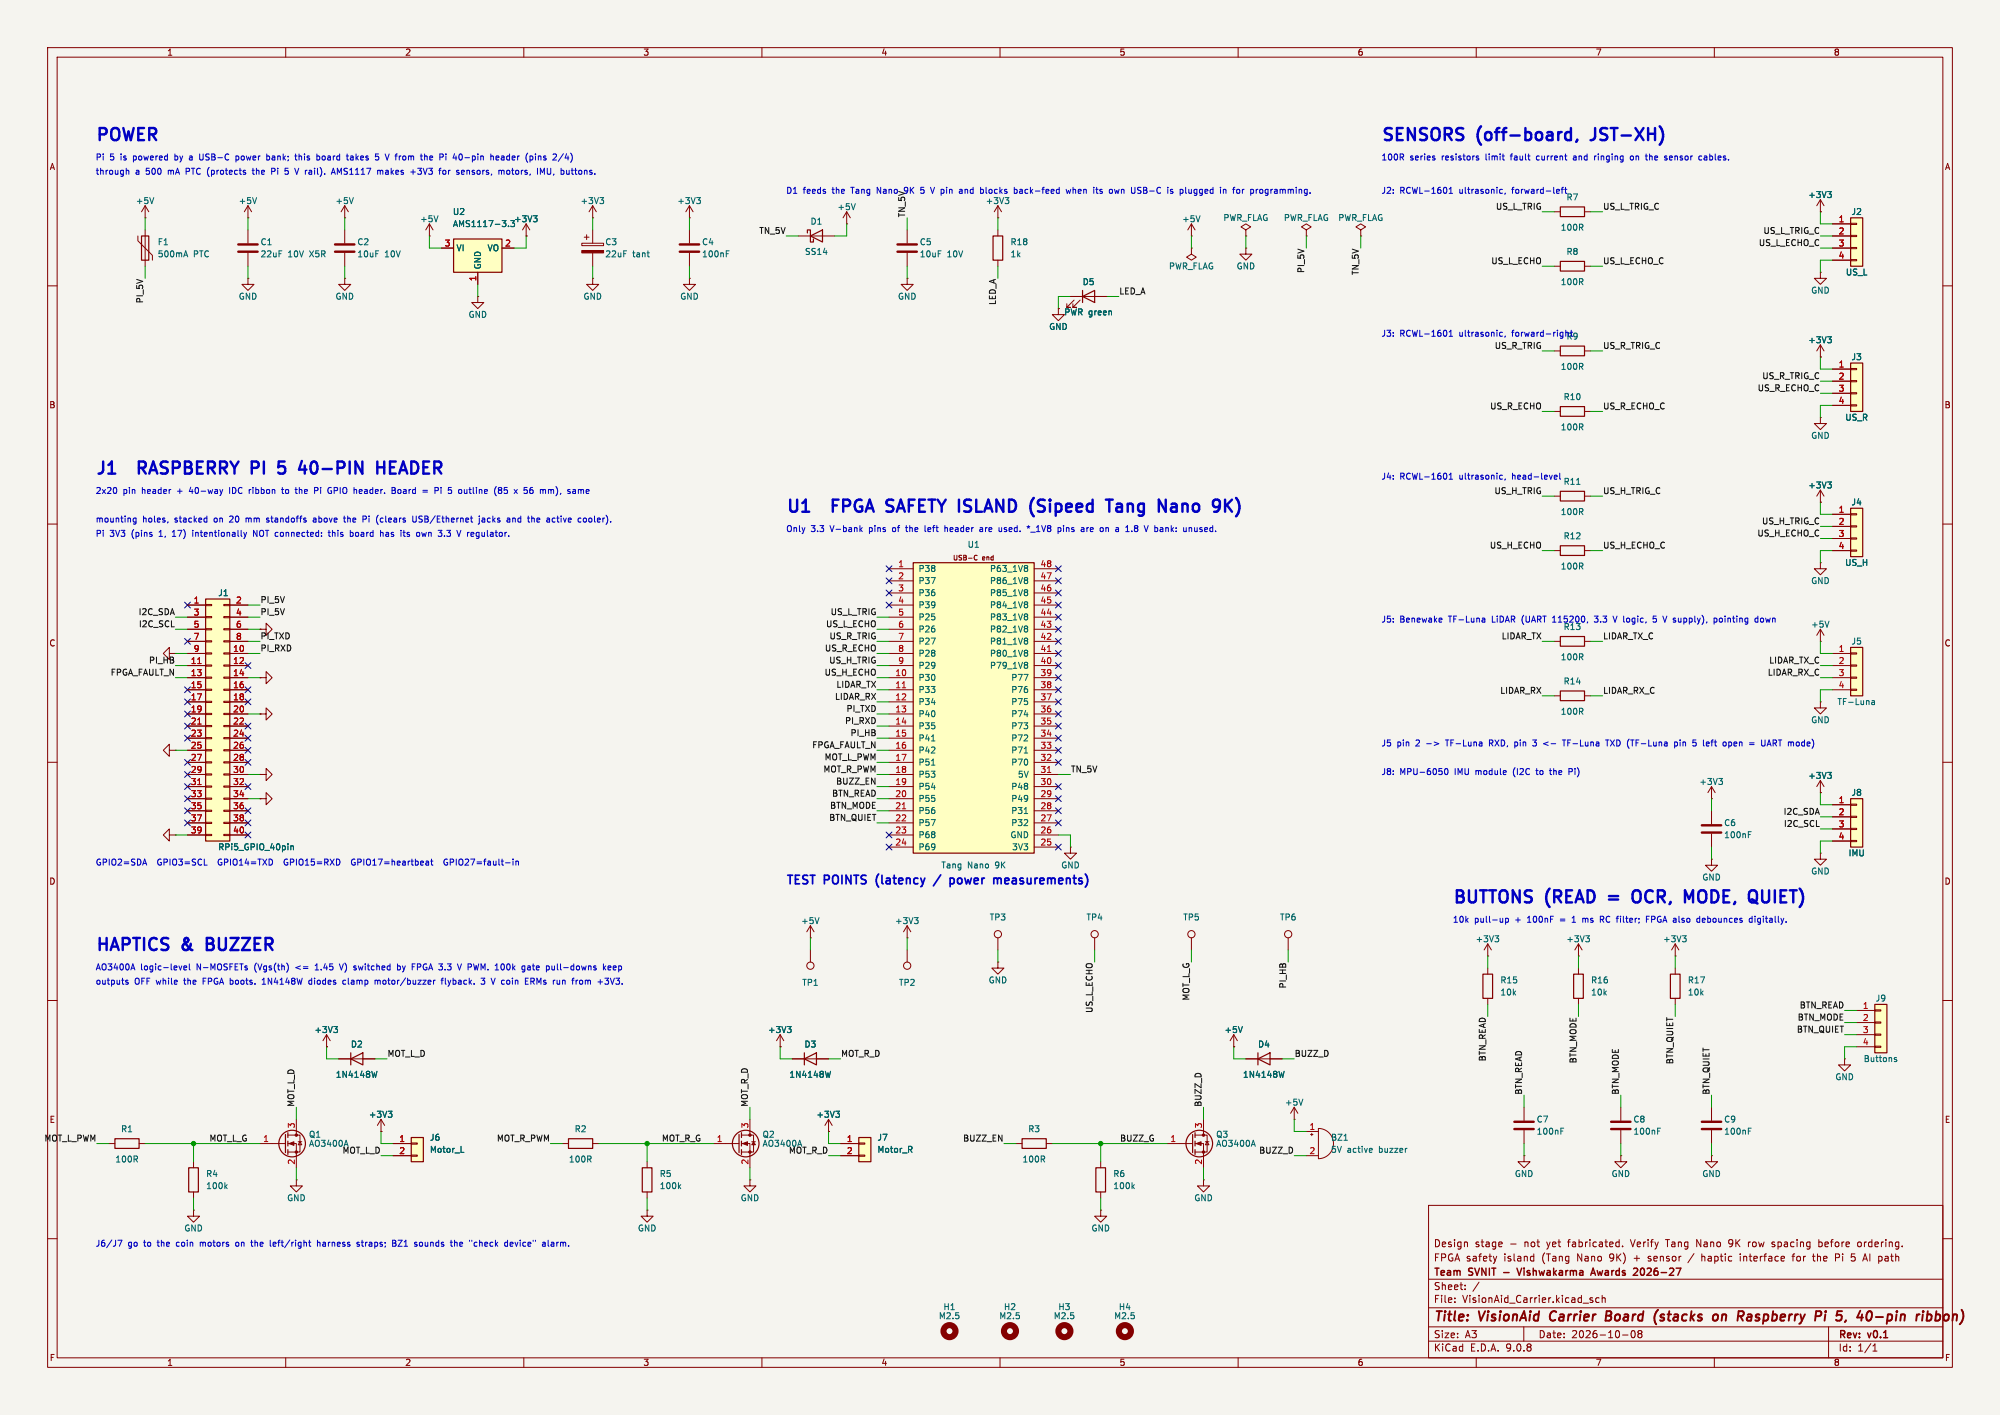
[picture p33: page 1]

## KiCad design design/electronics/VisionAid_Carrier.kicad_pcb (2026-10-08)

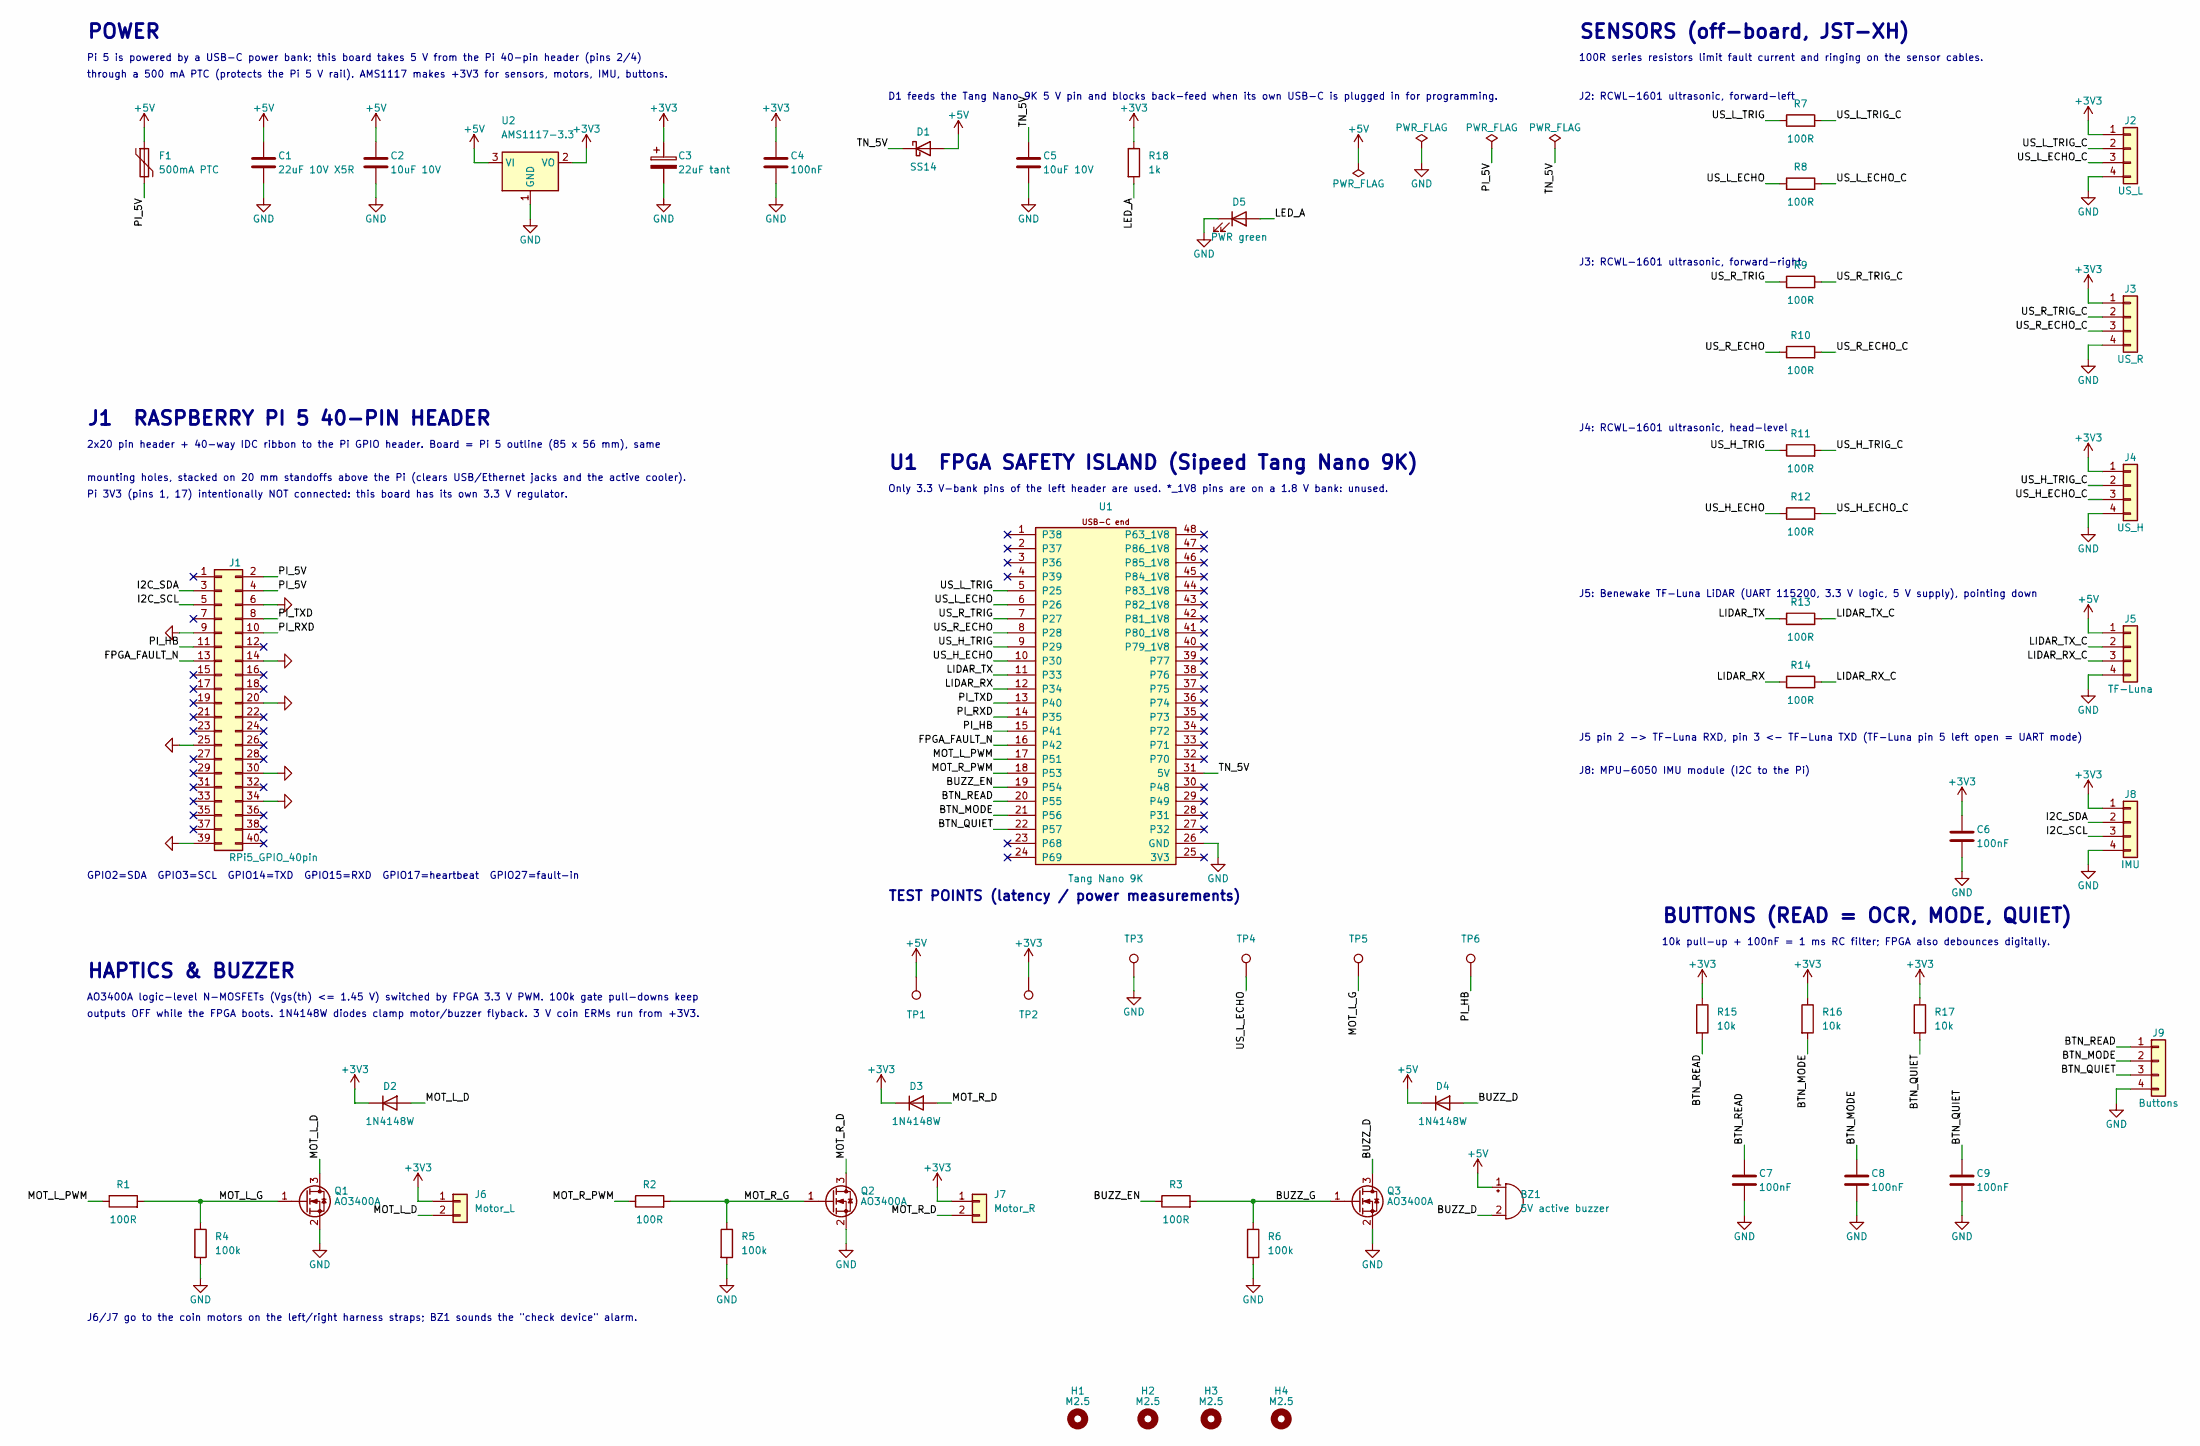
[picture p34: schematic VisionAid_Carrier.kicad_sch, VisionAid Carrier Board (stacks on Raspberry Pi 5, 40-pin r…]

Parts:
BZ1: 5V active buzzer; Buzzer_12x9.5RM7.6; MPN 12 mm 5 V active buzzer
C1: 22uF 10V X5R; C_1206_3216Metric
C2, C5: 10uF 10V; C_0805_2012Metric
C3: 22uF tant; CP_EIA-3528-21_Kemet-B
C4, C6, C7, C8, C9: 100nF; C_0603_1608Metric
D1: SS14; D_SMA; MPN SS14
D2, D3, D4: 1N4148W; D_SOD-123; MPN 1N4148W
D5: PWR green; LED_0603_1608Metric
F1: 500mA PTC; Fuse_1206_3216Metric; MPN 1206L050 / equivalent
H1, H2, H3, H4: M2.5; MountingHole_2.7mm_M2.5
J1: RPi5_GPIO_40pin; PinHeader_2x20_P2.54mm_Vertical
J2: US_L; JST_XH_B4B-XH-A_1x04_P2.50mm_Vertical; MPN JST B4B-XH-A
J3: US_R; JST_XH_B4B-XH-A_1x04_P2.50mm_Vertical; MPN JST B4B-XH-A
J4: US_H; JST_XH_B4B-XH-A_1x04_P2.50mm_Vertical; MPN JST B4B-XH-A
J5: TF-Luna; JST_XH_B4B-XH-A_1x04_P2.50mm_Vertical; MPN JST B4B-XH-A
J6: Motor_L; JST_XH_B2B-XH-A_1x02_P2.50mm_Vertical; MPN JST B2B-XH-A
J7: Motor_R; JST_XH_B2B-XH-A_1x02_P2.50mm_Vertical; MPN JST B2B-XH-A
J8: IMU; JST_XH_B4B-XH-A_1x04_P2.50mm_Vertical; MPN JST B4B-XH-A
J9: Buttons; JST_XH_B4B-XH-A_1x04_P2.50mm_Vertical; MPN JST B4B-XH-A
Q1, Q2, Q3: AO3400A; SOT-23; MPN AO3400A
R1, R2, R3, R7, R8, R9, R10, R11, R12, R13, R14: 100R; R_0603_1608Metric
R4, R5, R6: 100k; R_0603_1608Metric
R15, R16, R17: 10k; R_0603_1608Metric
R18: 1k; R_0603_1608Metric
TP1: +5V; TestPoint_Pad_D1.5mm
TP2: +3V3; TestPoint_Pad_D1.5mm
TP3: GND; TestPoint_Pad_D1.5mm
TP4: US_L_ECHO; TestPoint_Pad_D1.5mm
TP5: MOT_L_G; TestPoint_Pad_D1.5mm
TP6: PI_HB; TestPoint_Pad_D1.5mm
U1: Tang Nano 9K; TangNano9K_Module; MPN Sipeed Tang Nano 9K
U2: AMS1117-3.3; SOT-223-3_TabPin2; MPN AMS1117-3.3

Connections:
+3V3: C3.1, C4.1, C6.1, D2.1 (K), D3.1 (K), J2.1, J3.1, J4.1, J6.1, J7.1, J8.1, R15.1, R16.1, R17.1, R18.1, TP2.1, U2.2 (VO)
+5V: BZ1.1 (+), C1.1, C2.1, D1.2 (A), D4.1 (K), F1.1, J5.1, TP1.1, U2.3 (VI)
/BTN_MODE: C8.1, J9.2, R16.2, U1.21 (P56)
/BTN_QUIET: C9.1, J9.3, R17.2, U1.22 (P57)
/BTN_READ: C7.1, J9.1, R15.2, U1.20 (P55)
/BUZZ_D: BZ1.2 (-), D4.2 (A), Q3.3 (D)
/BUZZ_EN: R3.1, U1.19 (P54)
/BUZZ_G: Q3.1 (G), R3.2, R6.1
/FPGA_FAULT_N: J1.13, U1.16 (P42)
/I2C_SCL: J1.5, J8.3
/I2C_SDA: J1.3, J8.2
/LED_A: D5.2 (A), R18.2
/LIDAR_RX: R14.1, U1.12 (P34)
/LIDAR_RX_C: J5.3, R14.2
/LIDAR_TX: R13.1, U1.11 (P33)
/LIDAR_TX_C: J5.2, R13.2
/MOT_L_D: D2.2 (A), J6.2, Q1.3 (D)
/MOT_L_G: Q1.1 (G), R1.2, R4.1, TP5.1
/MOT_L_PWM: R1.1, U1.17 (P51)
/MOT_R_D: D3.2 (A), J7.2, Q2.3 (D)
/MOT_R_G: Q2.1 (G), R2.2, R5.1
/MOT_R_PWM: R2.1, U1.18 (P53)
/PI_5V: F1.2, J1.2, J1.4
/PI_HB: J1.11, TP6.1, U1.15 (P41)
/PI_RXD: J1.10, U1.14 (P35)
/PI_TXD: J1.8, U1.13 (P40)
/TN_5V: C5.1, D1.1 (K), U1.31 (5V)
/US_H_ECHO: R12.1, U1.10 (P30)
/US_H_ECHO_C: J4.3, R12.2
/US_H_TRIG: R11.1, U1.9 (P29)
/US_H_TRIG_C: J4.2, R11.2
/US_L_ECHO: R8.1, TP4.1, U1.6 (P26)
/US_L_ECHO_C: J2.3, R8.2
/US_L_TRIG: R7.1, U1.5 (P25)
/US_L_TRIG_C: J2.2, R7.2
/US_R_ECHO: R10.1, U1.8 (P28)
/US_R_ECHO_C: J3.3, R10.2
/US_R_TRIG: R9.1, U1.7 (P27)
/US_R_TRIG_C: J3.2, R9.2
GND: C1.2, C2.2, C3.2, C4.2, C5.2, C6.2, C7.2, C8.2, C9.2, D5.1 (K), J1.6, J1.9, J1.14, J1.20, J1.25, J1.30, J1.34, J1.39, J2.4, J3.4, J4.4, J5.4, J8.4, J9.4, Q1.2 (S), Q2.2 (S), Q3.2 (S), R4.2, R5.2, R6.2, TP3.1, U1.26 (GND), U2.1 (GND)

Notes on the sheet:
POWER
Pi 5 is powered by a USB-C power bank; this board takes 5 V from the Pi 40-pin header (pins 2/4)
through a 500 mA PTC (protects the Pi 5 V rail). AMS1117 makes +3V3 for sensors, motors, IMU, buttons.
D1 feeds the Tang Nano 9K 5 V pin and blocks back-feed when its own USB-C is plugged in for programming.
J1 RASPBERRY PI 5 40-PIN HEADER
2x20 pin header + 40-way IDC ribbon to the Pi GPIO header. Board = Pi 5 outline (85 x 56 mm), same
mounting holes, stacked on 20 mm standoffs above the Pi (clears USB/Ethernet jacks and the active cooler).
Pi 3V3 (pins 1, 17) intentionally NOT connected: this board has its own 3.3 V regulator.
GPIO2=SDA GPIO3=SCL GPIO14=TXD GPIO15=RXD GPIO17=heartbeat GPIO27=fault-in
U1 FPGA SAFETY ISLAND (Sipeed Tang Nano 9K)
Only 3.3 V-bank pins of the left header are used. *_1V8 pins are on a 1.8 V bank: unused.
SENSORS (off-board, JST-XH)
100R series resistors limit fault current and ringing on the sensor cables.
J2: RCWL-1601 ultrasonic, forward-left
J3: RCWL-1601 ultrasonic, forward-right
J4: RCWL-1601 ultrasonic, head-level
J5: Benewake TF-Luna LiDAR (UART 115200, 3.3 V logic, 5 V supply), pointing down
J5 pin 2 -> TF-Luna RXD, pin 3 <- TF-Luna TXD (TF-Luna pin 5 left open = UART mode)
J8: MPU-6050 IMU module (I2C to the Pi)
HAPTICS & BUZZER
AO3400A logic-level N-MOSFETs (Vgs(th) <= 1.45 V) switched by FPGA 3.3 V PWM. 100k gate pull-downs keep
outputs OFF while the FPGA boots. 1N4148W diodes clamp motor/buzzer flyback. 3 V coin ERMs run from +3V3.
J6/J7 go to the coin motors on the left/right harness straps; BZ1 sounds the "check device" alarm.
BUTTONS (READ = OCR, MODE, QUIET)
10k pull-up + 100nF = 1 ms RC filter; FPGA also debounces digitally.
TEST POINTS (latency / power measurements)

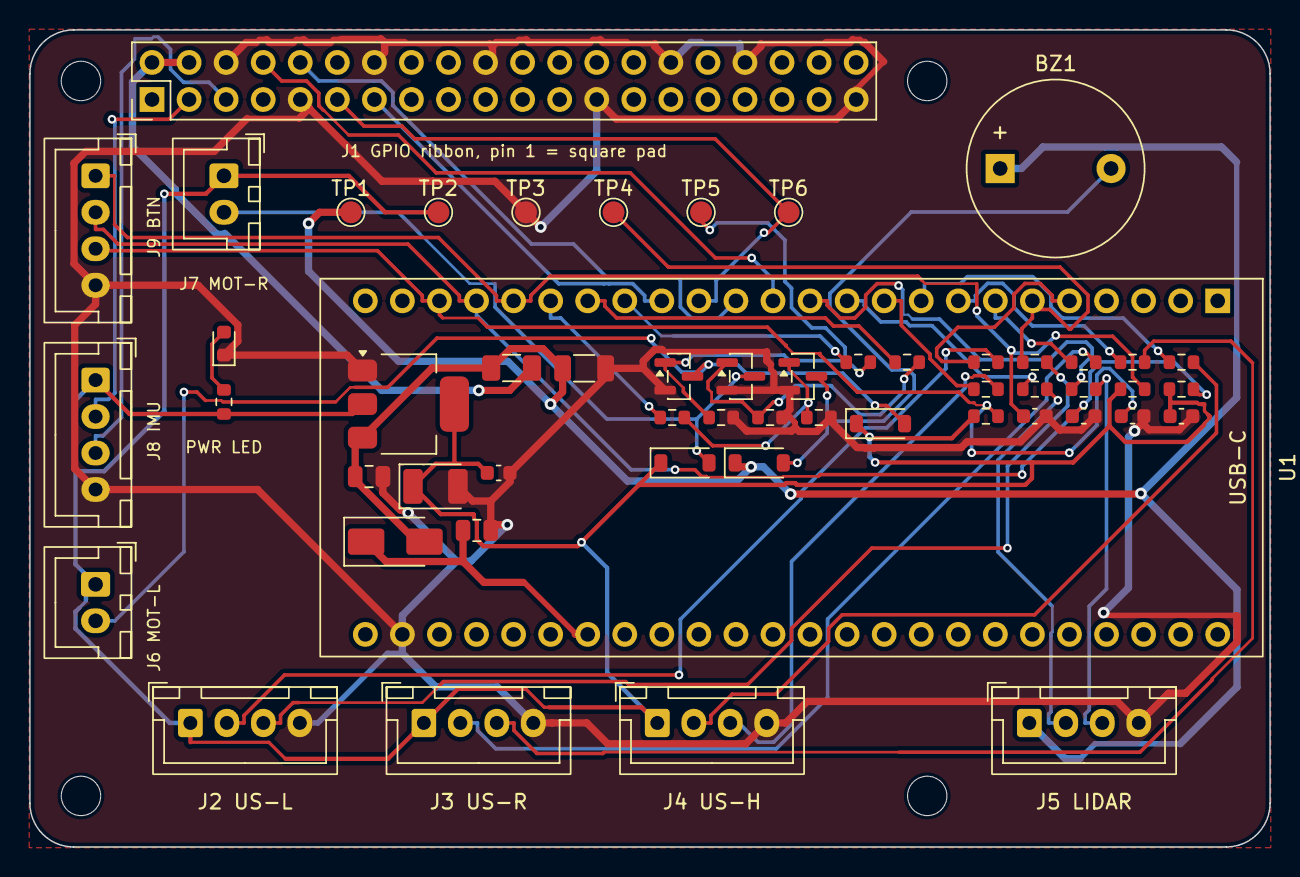
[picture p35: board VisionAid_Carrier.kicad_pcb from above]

Board: 2 copper layers, 85.0 x 56.0 mm, 58 parts (0 on the bottom side), 40 nets.

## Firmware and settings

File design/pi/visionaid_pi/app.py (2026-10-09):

"""VisionAid Raspberry Pi application (AI path). Same code runs on the Pi 5 and, for testing, on a laptop.

Loop (status frames arrive every 20 ms from the FPGA):
  1. decode FPGA status (protocol.StatusParser)
  2. IMU pitch -> floor-baseline command for the FPGA drop-off detector (floor.FloorBaseline)
  3. EVENT-TRIGGERED AI: run object detection only when the FPGA reports something within 3 m
     (power analysis: continuous AI ~3.1 h battery, event-triggered ~4.3 h assuming ~50 % AI duty), at most every 0.5 s
  4. READ button (flag from the FPGA) -> OCR -> speech
  5. alert manager -> Piper speech (safety messages first)
  6. toggle the heartbeat GPIO so the FPGA watchdog knows the AI path is alive
On a laptop: --replay feeds the bytes the Verilog FPGA produced in simulation and --images stands in for the camera.
On the Pi:   --serial /dev/ttyAMA0 --camera  (picamera2, gpiozero, smbus2 for the MPU-6050).
"""
import argparse
import glob
import os
import time

import cv2

from .protocol import StatusParser
from .floor import FloorBaseline
from .alerts import AlertManager, ZONE_SPEAK_MM
from .vision import Detector, hazards
from .speech import Reader, Speaker

MODELS = os.environ.get('VISIONAID_MODELS', '/tmp/visionaid-tools/models')


class ReplayLink:
    """Plays back FPGA->Pi bytes recorded from the Verilog simulation, 11 bytes per 20 ms frame."""
    def __init__(self, hexfile):
        self.data = bytes(int(x, 16) for x in open(hexfile).read().split())
        self.pos = 0
        self.sent = []

    def read(self, n=11):
        chunk = self.data[self.pos:self.pos + n]
        self.pos += n
        return chunk

    def write(self, b):
        self.sent.append(bytes(b))

    def done(self):
        return self.pos >= len(self.data)


class ImageCamera:
    def __init__(self, folder):
        self.files = sorted(glob.glob(os.path.join(folder, '*.jpg')))
        self.i = 0

    def capture(self):
        f = self.files[self.i % len(self.files)]
        self.i += 1
        return cv2.imread(f)


def run(link, camera, speak_dir, log, imu_pitch=lambda: 0.0, heartbeat=lambda: None, realtime=False):
    parser, floor, alerts = StatusParser(), FloorBaseline(), AlertManager(cooldown_s=4.0)
    det = Detector(os.path.join(MODELS, 'yolov5n.onnx'))
    reader = Reader()
    voice = Speaker(os.path.join(MODELS, 'en_US-lessac-medium.onnx'))
    stats = {'frames': 0, 'detections_run': 0, 'ocr_run': 0, 'spoken': 0, 'floor_cmds': 0}
    last_det, t_sim, n_spoken = -1e9, 0.0, 0
    while not link.done():
        frames = parser.feed(link.read())
        for st in frames:
            stats['frames'] += 1
            t_sim += 0.020                                       # frame period of the FPGA status stream
            cmd = floor.command(imu_pitch())
            if cmd:
                link.write(cmd)
                stats['floor_cmds'] += 1
            dets = []
            nearest = min(st.left_mm, st.right_mm, st.head_mm)
            if nearest < ZONE_SPEAK_MM and t_sim - last_det >= 0.5:          # event-triggered AI
                dets, _ = det.detect(camera.capture())
                dets = hazards(dets)
                stats['detections_run'] += 1
                last_det = t_sim
            text = None
            if st.read_pressed:
                text, _ = reader.read(camera.capture())
                stats['ocr_run'] += 1
            for prio, phrase in alerts.update(st, dets, text):
                wav = os.path.join(speak_dir, 'say_%03d.wav' % n_spoken)
                voice.synth(phrase, wav)
                n_spoken += 1
                stats['spoken'] += 1
                log.write('%8.2f s  P%d  %-36s L=%5s R=%5s H=%5s floor=%3d cm flags=%s\n' % (
                    t_sim, prio, phrase, st.left_mm, st.right_mm, st.head_mm, st.lidar_cm, format(st.flags, '08b')))
            heartbeat()
            if realtime:
                time.sleep(0.02)
    return stats


def main():
    ap = argparse.ArgumentParser()
    ap.add_argument('--replay', help='hex file of FPGA->Pi bytes (from the Verilog testbench)')
    ap.add_argument('--images', help='folder of JPEGs standing in for the camera')
    ap.add_argument('--out', default='results/replay')
    a = ap.parse_args()
    os.makedirs(a.out, exist_ok=True)
    with open(os.path.join(a.out, 'replay_log.txt'), 'w') as log:
        stats = run(ReplayLink(a.replay), ImageCamera(a.images), a.out, log)
        log.write('\nSTATS %s\n' % stats)
    print(stats)


if __name__ == '__main__':
    main()

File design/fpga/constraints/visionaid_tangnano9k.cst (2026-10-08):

// VisionAid safety island - Tang Nano 9K (GW1NR-LV9QN88PC6/I5) physical constraints.
// Pin numbers from the Sipeed Tang Nano 9K pin map; all user I/O on the 3.3 V banks (left header).
IO_LOC "clk" 52;
IO_PORT "clk" IO_TYPE=LVCMOS33 PULL_MODE=UP;
IO_LOC "rst_n" 4;
IO_PORT "rst_n" PULL_MODE=UP;  // on-board button S1
IO_LOC "us_trig[0]" 25;
IO_PORT "us_trig[0]" IO_TYPE=LVCMOS33 DRIVE=8;
IO_LOC "us_echo[0]" 26;
IO_PORT "us_echo[0]" IO_TYPE=LVCMOS33 PULL_MODE=DOWN;
IO_LOC "us_trig[1]" 27;
IO_PORT "us_trig[1]" IO_TYPE=LVCMOS33 DRIVE=8;
IO_LOC "us_echo[1]" 28;
IO_PORT "us_echo[1]" IO_TYPE=LVCMOS33 PULL_MODE=DOWN;
IO_LOC "us_trig[2]" 29;
IO_PORT "us_trig[2]" IO_TYPE=LVCMOS33 DRIVE=8;
IO_LOC "us_echo[2]" 30;
IO_PORT "us_echo[2]" IO_TYPE=LVCMOS33 PULL_MODE=DOWN;
IO_LOC "lidar_tx" 33;
IO_PORT "lidar_tx" IO_TYPE=LVCMOS33;
IO_LOC "lidar_rx" 34;
IO_PORT "lidar_rx" IO_TYPE=LVCMOS33 PULL_MODE=UP;
IO_LOC "pi_txd" 40;
IO_PORT "pi_txd" IO_TYPE=LVCMOS33 PULL_MODE=UP;  // from Pi GPIO14
IO_LOC "pi_rxd" 35;
IO_PORT "pi_rxd" IO_TYPE=LVCMOS33;  // to Pi GPIO15
IO_LOC "pi_hb" 41;
IO_PORT "pi_hb" IO_TYPE=LVCMOS33 PULL_MODE=DOWN;  // from Pi GPIO17
IO_LOC "fpga_fault_n" 42;
IO_PORT "fpga_fault_n" IO_TYPE=LVCMOS33;  // to Pi GPIO27
IO_LOC "mot_l" 51;
IO_PORT "mot_l" IO_TYPE=LVCMOS33 DRIVE=8;
IO_LOC "mot_r" 53;
IO_PORT "mot_r" IO_TYPE=LVCMOS33 DRIVE=8;
IO_LOC "buzz" 54;
IO_PORT "buzz" IO_TYPE=LVCMOS33 DRIVE=8;
IO_LOC "btn_read_n" 55;
IO_PORT "btn_read_n" IO_TYPE=LVCMOS33 PULL_MODE=UP;
IO_LOC "btn_mode_n" 56;
IO_PORT "btn_mode_n" IO_TYPE=LVCMOS33 PULL_MODE=UP;
IO_LOC "btn_quiet_n" 57;
IO_PORT "btn_quiet_n" IO_TYPE=LVCMOS33 PULL_MODE=UP;
IO_LOC "led_n[0]" 10;
IO_LOC "led_n[1]" 11;
IO_LOC "led_n[2]" 13;
IO_LOC "led_n[3]" 14;
IO_LOC "led_n[4]" 15;
IO_LOC "led_n[5]" 16;

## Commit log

2026-10-08 Stage 2 design baseline: KiCad carrier board, FPGA safety island + testbench, FreeCAD pod + FEA, BOM, proposal v2
    [BaseShell.step, BaseShell.stl, FrontLid_with_housings.step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]
2026-10-08 Add finger-root fillet (FEA v2) to pod CAD; GUI screenshots (FreeCAD, KiCad DRC/ERC, GTKWave); tool launcher fixes
    [BaseShell.step, BaseShell.stl, FrontLid_with_housings.step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]
2026-10-08 Fix KiCad 3D models (local plugin path); add Tang Nano 9K 3D model; interference check with real module -> shell depth 44->48 mm; refreshed renders and screenshots
    [BaseShell.step, BaseShell.stl, FrontLid_with_housings.step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]
2026-10-08 Stage 2 design deck (editable PPTX, 18 slides, template order/style) + build script and assets
2026-10-08 Proof of concept: real P&R on GW1NR-9 (67.9 MHz, bitstream), Vivado Zynq cross-check, Pi software (protocol, YOLO, OCR, Piper TTS, alerts, IMU floor baseline, event-triggered AI), FPGA<->Python cross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
2026-10-08 Deck v2 (20 slides): real FPGA P&R + Vivado, AI-path proof of concept, sensor coverage/drop-off analysis, updated specs/battery/risks/references
2026-10-09 Numbers audit: every deck figure re-verified against logs, reports, sources and live prices
    - BOM re-quoted 9 Oct 2026: Rs 33,945 (Rs 3,945 over grant); Pi 5, Tang Nano 9K, TF-Luna out of stock
    - Runtime unified to 3.1 / 4.3 / 7.2 h (event-triggered assumes ~50 % AI duty); one component list for sheet + analysis
    - Latency: 136 ns on waveform vs <= 214 ns conservative testbench bound, explained
    - Citations checked: Manduchi survey stats (307 resp., 13 % / 7 % monthly), OrCam US$4,250, SmartCane 2016
    - Detection chart: AP50 per class with n, large-object recall only where >= 5 samples; e2e label clarified
    - FEA convergence wording (<= 3 %), v2 FoS 8.7 (all runs >= 8.6)
    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
    [VisionAid_BOM_Power.xlsx]
2026-10-09 Model training: pothole detector fine-tuned (YOLO11n) on public CC BY 4.0 data, measured on held-out test
    - Held-out test (100 images, 269 potholes): P 0.64, R 0.30, mAP50 0.37, mAP50-95 0.15; ONNX 26 ms laptop CPU
    - Train/test overlap check (name + perceptual hash incl. flips): none
    - New deck slide 13 (21 slides); image-source exception for the dataset photos noted on the sources slide
    [results.csv]
2026-10-11 Root-cause fixes + real Indian pothole data + verified FPGA/CAD rebuilds
    RTL: round (not truncate) the ultrasonic distance calc; parameterise
    va_alerts counter widths with $clog2 so they can't silently overflow
    if DROP_FRAMES/STALE_MS are retuned later.
    Pi: clamp the LiDAR beam angle in floor.py - extreme forward lean
    previously threw ZeroDivisionError in the main loop.
    Pothole detector: pooled the small public Ryukijano set with 1,530
    real Indian road photos from RDD2020 (Arya et al., IEEE Big Data
    2020), re-split train/valid/test with zero photo leakage, retrained.
    Test set grew from 100 non-Indian to 330 images (230 of them real
    Indian roads); recall improved 0.30 -> 0.42 on this harder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
2026-10-22 Replace photo placeholders with system data-flow diagram on Maker Journey slide
    No team photos were available before the deadline, so the two "PHOTO TO ADD"
    placeholders are replaced with a simplified sensors -> FPGA safety island ->
    haptics/Pi 5 AI -> Bluetooth flow diagram, consistent with the full
    architecture on slide 7. Application ID and Team ID were already set to the
    single Vishwakarma ID (VK26-IITI-HT-0261) everywhere in the deck.
